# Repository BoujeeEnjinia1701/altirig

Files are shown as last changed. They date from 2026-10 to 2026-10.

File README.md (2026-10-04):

# AltiRig

     

**Area:** Aerial robotics · **TRL:** 3 of 9 (proof of concept on paper) · **Value-engineering target:** about $1,000 USD (estimated cost of the constructable design about $3,865 USD, using surplus steel and a host lab's DC supply and pump) · **Difficulty:** 3 of 5

A test chamber that simulates thin air at 5,000 m so propellers and motors can be proven before going up the mountain.

> CONCEPT, NOT FOR FABRICATION. AltiRig is a TRL 3 design on paper: it has not been built or tested.

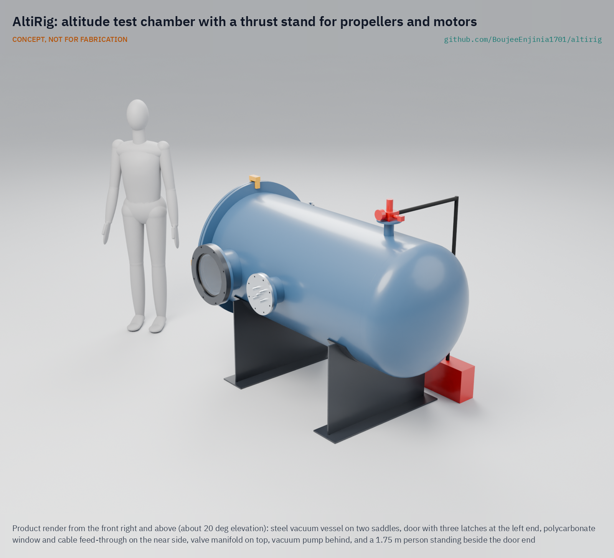
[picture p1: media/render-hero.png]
AltiRig: altitude test chamber with a thrust stand for propellers and motors, product render


[Exploded render](media/render-exploded.png) · [Detail render](media/render-detail.png) · [Interactive 3D model](media/viewer.html) · [Concept blueprint (PDF)](media/concept-blueprint.pdf) · [General arrangement (PDF)](cad/drawings/ALR-DWG-001.pdf) · [Calculations](docs/04-calcs/01-sizing.md) · [Prototype build plan](docs/05-build-plan.md) · [Design decisions](docs/06-design-decisions.md) · [Review note](docs/REVIEW.md)

> **Not certified pressure or test equipment.** AltiRig is a TRL 3 concept, not released for fabrication. It is a vacuum vessel with a spinning propeller inside; see [Safety](#safety).

## Concept rationale

AltiRig is the test chamber of the Kitewright civilian drone family. It is a sealed vessel with a thrust stand inside. A vacuum pump lowers the air pressure until the air density matches 5,000 m, and the stand then measures a propeller and motor's thrust, torque, speed and electrical power as they would be in the Himalaya. The same run can be repeated at any density between sea level and the target altitude.

Proving propellers and motors on the bench before carrying them up a mountain saves expeditions and aircraft. An open, documented chamber that a university lab or a welding shop and maker space can build (value-engineering target USD 1,000; the constructable design is estimated at USD 3,865 with surplus steel and a host lab's DC supply and pump) lets anyone planning high-altitude flights check their numbers first, and lets the Kitewright Lift and Range frames publish thrust data measured, not guessed. ColdCell packs are not tested inside the chamber in this version.

## Burning platform

Propeller thrust depends on air density as well as on the propeller's shape and speed ([Tyto Robotics](https://www.tytorobotics.com/blogs/articles/how-to-measure-propeller-performance-coefficients)). At 5,000 m in the standard atmosphere the density is 0.736 kg/m3, about 60% of the sea-level value of 1.225 kg/m3, and the pressure is 54 kPa ([Engineering ToolBox](https://www.engineeringtoolbox.com/standard-atmosphere-d_604.html)). A drone that hovers comfortably at the workshop can be close to its limit at a Himalayan lake. Our earlier estimate is that at 5,000 m and -20 C a multirotor hovers for only about 47% of its sea-level time (estimate).

Demand to fly this high is real. DJI ran delivery tests between 5,300 m and 6,000 m on Everest in 2024 ([DJI, 2024](https://www.dji.com/media-center/announcements/dji-completes-world-first-drone-delivery-tests-on-mount-everest-en)), and India's glacial lake work takes place above 4,500 m ([ThePrint, 2024](https://theprint.in/india/govt-approves-rs-150-crore-for-glacial-lake-outburst-flood-risk-mitigation-programme-for-4-states/2232525/)). Yet common thrust stands, such as Tyto Robotics' Flight Stand 50, measure thrust, torque and power at the conditions of the room they sit in ([Tyto Robotics](https://www.tytorobotics.com/pages/flight-stand-50)). Commercial altitude chambers exist for testing equipment at low pressure ([Sanatron](https://www.sanatron.com/articles/altitude-test-chamber-how-vacuum-chambers-simulate-high-altitudes.php)), but they are built for industry, not for a small team choosing propellers.

## Where it could be used

### By industry

| Industry | Use |
| --- | --- |
| Drone design and research | Propeller and motor selection for high-altitude multirotors and quadplanes |
| Mountain rescue and disaster agencies | Checking that a drone will hover with margin at the altitude of a call-out before deployment |
| Universities and technical colleges | Teaching lab for propeller aerodynamics and the effect of air density |
| Glaciology and survey | Verifying survey drones before summer campaigns above 4,500 m |
| Battery and electronics testing | Low-pressure checks of battery packs, connectors and electronics for arcing or seal problems |

### By country or region

| Country or region | Why it matters there |
| --- | --- |
| Nepal | Drone delivery tests on Everest ran between 5,300 m and 6,000 m in 2024 ([DJI, 2024](https://www.dji.com/media-center/announcements/dji-completes-world-first-drone-delivery-tests-on-mount-everest-en)). |
| India (Himalaya) | Survey and mitigation work on 189 high-risk glacial lakes takes place above 4,500 m ([ThePrint, 2024](https://theprint.in/india/govt-approves-rs-150-crore-for-glacial-lake-outburst-flood-risk-mitigation-programme-for-4-states/2232525/)). |
| India (Ladakh) | The Gya glacier snout that fed the 2014 outburst flood lies at about 5,450 m ([Science of the Total Environment](https://www.sciencedirect.com/science/article/abs/pii/S0048969720375392)). |
| Pakistan (Karakoram) | The 2018 Broad Peak search found Rick Allen by drone at about 7,500 m ([Explorersweb, 2018](https://explorersweb.com/rick-allen-found-alive-on-broad-peak/)). |

## What sparked the idea

In July 2018 a small consumer drone found the climber Rick Allen alive at about 7,500 m on Broad Peak, 36 hours after he fell from an ice cliff ([Explorersweb, 2018](https://explorersweb.com/rick-allen-found-alive-on-broad-peak/)). That the drone flew at all in air that thin was notable. For the Kitewright family to fly reliably at 5,000 m and above, its propellers and motors need to be tested in that air before they go up, and AltiRig is the bench that makes that possible at sea level.

## Problem

Propellers and motors make much less thrust in the thin air of the high Himalaya, but most makers can only test them at the altitude of their workshop. They find out what works at 5,000 m by flying there, which is slow, costly and risky.

Full problem statement: [docs/01-problem.md](docs/01-problem.md)

## Concept

A sealed test chamber with a thrust stand that pulls the air down to the density of 5,000 m altitude, so makers measure propeller and motor thrust and power as they will be in the Himalaya.

The constructable design is a horizontal steel vessel made from a surplus 813 mm (32 in) pipe offcut and two surplus tank heads, one of them the door, on two saddles. Inside, a flexure thrust stand measures thrust from 0 to 50 N and torque to 2 N m on propellers up to 380 mm. The density of 5,000 m (0.736 kg/m3) is reached at about 61.9 kPa at room temperature in about 3 minutes. The vessel is designed for full vacuum with a collapse factor of 6.7. On paper all twelve requirements are met: an 80 % open baffle keeps the chamber effect (R6) to an estimated 1.8 % to 3.3 %, and the cost (R10), restated by Amish to USD 4,000, is estimated at USD 3,865 (see the [review note](docs/REVIEW.md)).

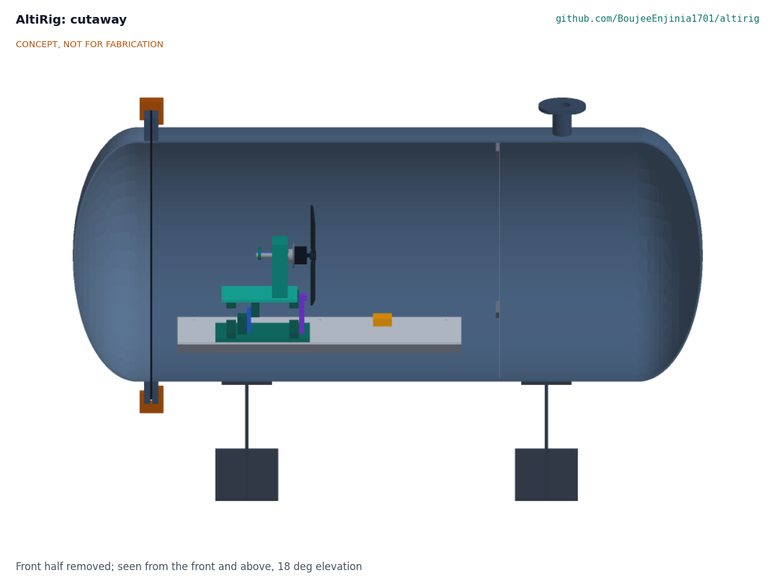
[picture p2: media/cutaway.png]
AltiRig cutaway: stand, propeller, baffle


Full design precis: [docs/02-concept.md](docs/02-concept.md) · Requirements: [docs/03-requirements.md](docs/03-requirements.md)

## Key components

- Pressure vessel: 813 x 6.35 mm steel pipe shell, 2:1 ellipsoidal tank heads, flange rings and a sponge-gasket door held shut by air
- Viewing port: 20 mm polycarbonate window, outside the propeller's fragment zone
- Vacuum pump (the host lab's, 170 L/min), relief valve, normally-open bleed valve and gauge on one manifold
- Thrust and torque stand: spring-steel flexures, 10 kg thrust cell, torque head on bearings with a 5 kg cell
- Speed sensor: optical, one pulse a turn
- Pressure, temperature and humidity sensors on the deck
- Sealed feed-through plate with potted IP68 cable glands
- Removable 80 % open perforated baffle
- Control cabinet: logger, contactor for the host lab's 1,500 W motor supply, emergency stop, door interlock and arming key

## Building the prototype

The [prototype build plan](docs/05-build-plan.md) shows how to make each of the twenty-two made parts, with a making sketch for each, ten joint close-ups and twenty assembly steps. The vessel is cut and welded by a welding shop from surplus pipe, plate and two surplus tank heads; the stand is cut, drilled and bored from aluminium and spring-steel shim. Before any pump-down a qualified engineer reviews the vessel calculation, and the first pump-down is a proof test behind a guard. The plan is a plan, not yet built.

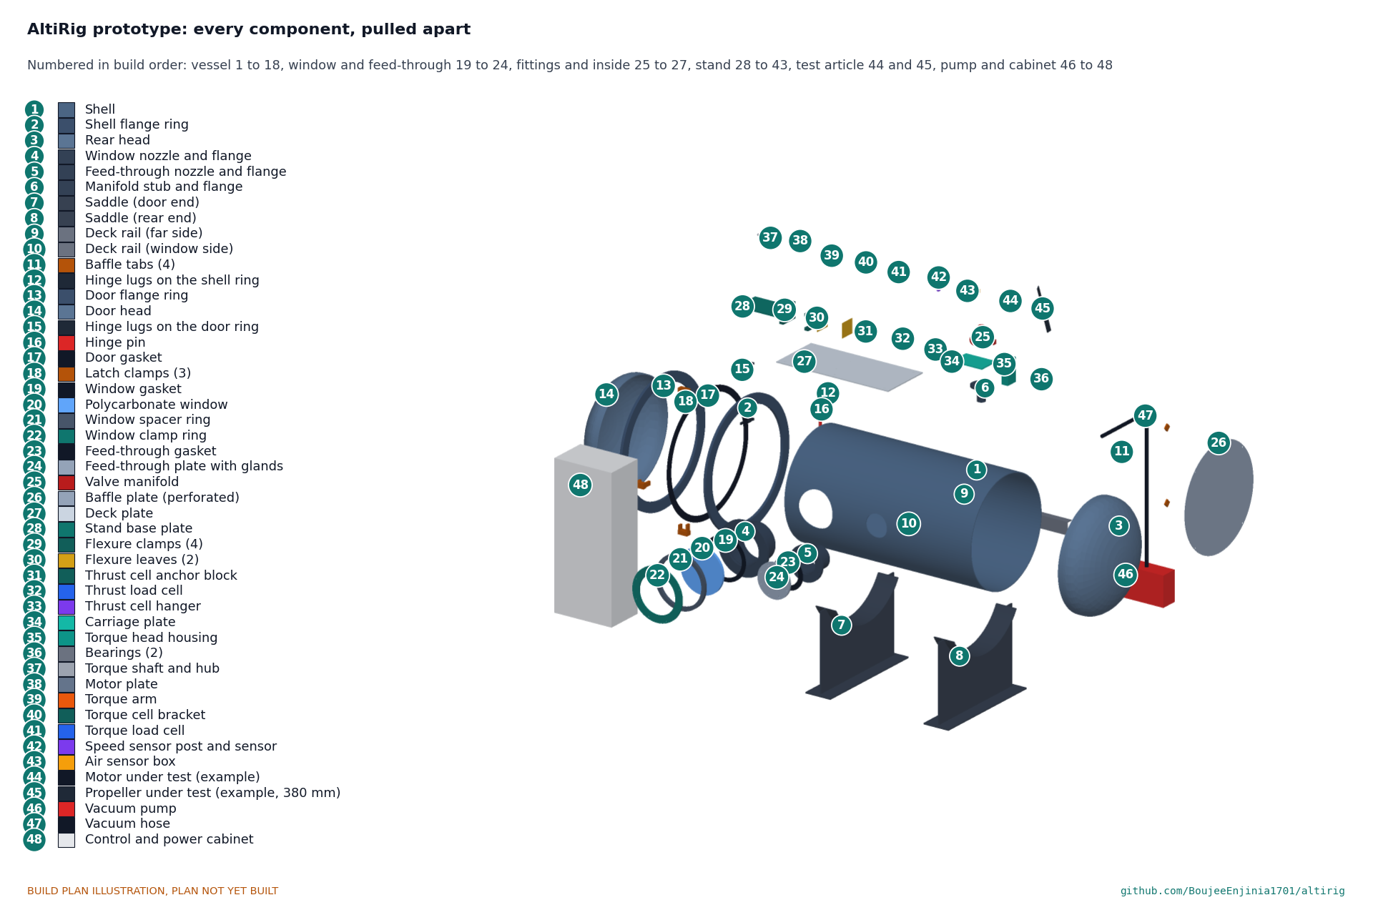
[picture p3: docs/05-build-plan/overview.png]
Every component of AltiRig, pulled apart and numbered in build order


## Safety

> Published as an open engineering reference, not certified pressure or test equipment.
>
> The chamber is a vacuum vessel: at the 5,000 m density point the outside air pushes on it with about 39 kPa, and with up to 55 kPa at the relief setting, roughly 4 to 5.6 tonnes-force per square metre of wall. Collapse or window failure can throw fragments. The vessel is designed for full vacuum with a collapse factor of 6.7, a relief valve stops the chamber at 46.3 kPa absolute, the window is polycarbonate (never acrylic or glass), and the first pump-down is a proof test behind a guard after a qualified engineer has reviewed the calculation.
>
> The door is held shut by up to 24 kN under vacuum. Vent the chamber before unlatching it; never force it.
>
> Spinning propellers can shatter. The window and feed-through sit outside the propeller's fragment zone, the steel shell contains a broken blade, and the motor can only be armed with the door latched and the key turned.
>
> No lithium or sodium-ion pack goes inside the chamber in this version: a fire in a closed vessel is a pressure and fume hazard.
>
> The pump and motor supply run from mains through a 30 mA residual current device with the vessel earthed; the emergency stop removes motor and pump power and the bleed valve opens on loss of power.
>
> This design is published as an open engineering reference. It is not certified equipment.

## Repository layout

| Folder | Contents |
| --- | --- |
| `docs/` | Problem, concept, requirements, calculations and design decisions |
| `cad/src/` | build123d Python source, the source of truth for all geometry |
| `cad/step/`, `cad/stl/` | Exported models for FreeCAD, other CAD tools and printing |
| `cad/drawings/` | 2D sketches and dimensioned drawings |
| `bom/` | Bill of materials |
| `electronics/` | KiCad schematics and PCB layouts |
| `firmware/` | Microcontroller code |
| `media/` | Renders, perspectives and photos |
| `build-log/` | Dated prototyping notes |

## Documentation

Controlled documents follow the portfolio [documentation standard](.kit/STANDARDS.md). Each carries a document ID (ALR-PRC-001 for the precis), a version and a revision history. Branded PDFs are built with `python .kit/render.py` and attached to GitHub Releases when a document is tagged, for example `ALR-PRC-001/v1.0`.

## Credits

Designed by Amish Chadha at Design Molecule Labs. See [CONTRIBUTORS.md](CONTRIBUTORS.md) for roles. To cite this design, use [CITATION.cff](CITATION.cff) (GitHub shows it as "Cite this repository").

AI assistance (Claude) was used to accelerate prototype documentation and first-pass research. Design direction and all decisions are Amish Chadha's, recorded in this repository's decision records (`docs/decisions/`).

## Licenses

- **Hardware** (CAD, drawings, BOM, electronics): [CERN-OHL-S v2](LICENSE)
- **Software** (firmware, scripts, notebooks): [MIT](LICENSE-SOFTWARE)

A project of the [Design Molecule](https://designmolecule.com) lab.

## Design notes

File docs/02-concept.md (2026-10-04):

---
doc_id: ALR-PRC-001
title: AltiRig design precis
project: AltiRig
doc_type: Precis
version: "0.4"
status: Draft
date: '2026-10-03'
author: Amish Chadha
license: CERN-OHL-S-2.0
revisions:
- version: "0.1"
  date: '2026-09-30'
  author: Amish Chadha
  change: Initial scaffold
- version: "0.2"
  date: '2026-10-03'
  author: Amish Chadha
  change: TRL 2 concept; vessel type, stand, density matching, safety design and media decided under Amish's 2026-10-03 pre-approval (ALR-DDR-001)
- version: "0.3"
  date: '2026-10-03'
  author: Amish Chadha
  change: TRL 3; numbers from ALR-CAL-001 and the constructable design (ALR-DDR-002)
- version: "0.4"
  date: '2026-10-03'
  author: Amish Chadha
  change: "Amish's decisions 41B (80 % open baffle) and 42B (surplus pipe and heads, host lab's DC supply and pump), ALR-DDR-003"
---

# AltiRig design precis

A test chamber that simulates thin air at 5,000 m so propellers and motors can be proven before going up the mountain.

AltiRig is a horizontal steel vacuum vessel, 813 mm in diameter and about 2 m long, with a flexure thrust stand inside. A vacuum pump lowers the pressure until the air inside has the density of 5,000 m (0.736 kg/m3, about 61.9 kPa at 20 °C), and the stand measures a propeller's thrust, torque and speed with the motor's voltage and current. The vessel is built from a surplus steel pipe offcut and two surplus tank heads, one of which is the door; air pressure holds the door shut while the chamber is under vacuum.

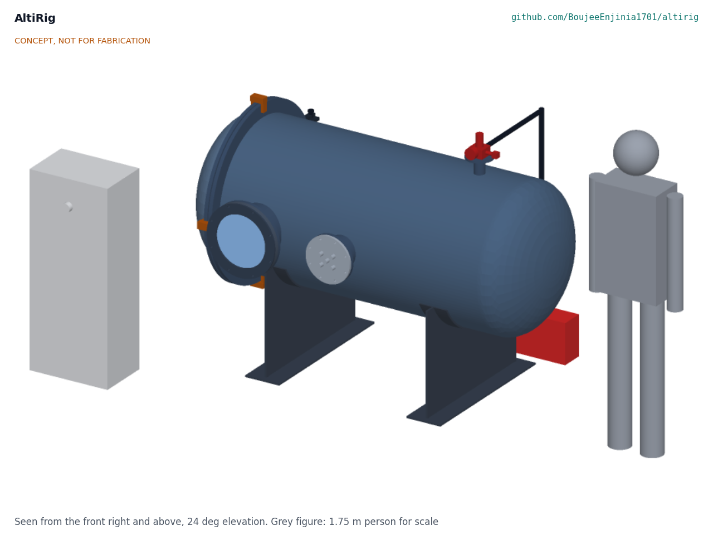
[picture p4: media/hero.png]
AltiRig concept with a 1.75 m person for scale


*Figure 1. AltiRig, seen from the front right and above: vessel on two saddles, door and latches at the left end, window and feed-through on the near side, valve manifold on top, pump behind, control cabinet in front.*

## How it works

The motor and propeller under test sit on the axis of the vessel, 510 mm in from the door, blowing toward the rear head. The operator closes the door, latches it and starts the pump. The controller reads two pressure sensors and two temperature probes inside, works out the air density, and holds it at the chosen value by switching the pump and opening a bleed valve that lets room air back in. As the motor runs, its heat warms the air; the controller raises the pressure a little to keep the density steady.

The propeller's thrust moves the carriage of the stand by about a tenth of a millimetre on two spring-steel leaves, and a load cell between the carriage and the base measures it. The motor is mounted on a shaft that turns freely in two bearings; its reaction torque presses an arm onto a second load cell. An optical sensor counts the blades. Motor power comes from the host lab's 1,500 W DC supply, switched by the interlocked contactor in the control cabinet, through a speed controller and a sealed feed-through plate. Everything is logged to CSV at 20 Hz.

Inside a closed vessel the propeller drives a loop of air: down the middle, through an 80 % open perforated baffle, round the rear head and back along the wall. To find what the loop does to the readings, each propeller is also run at ambient pressure and compared with an open-air stand; that comparison is published with the data.

AltiRig cutaway

*Figure 2. Cutaway with the window side removed: stand and motor on the deck at the door end, the propeller plane, the baffle and the rear head.*

## Components

*Table 1. Main components (numbers match `bom/bom.csv`).*

| # | Component | Role |
| --- | --- | --- |
| 1 | Shell | 813 x 6.35 mm steel pipe offcut, 1,500 mm long; the body of the vessel |
| 2 | Flange rings | 20 mm steel rings on the shell end and on the door; the door seals on a sponge gasket between them |
| 3 | Dished heads | Two bought 2:1 ellipsoidal heads: one welded to the rear, one is the door |
| 4 | Window nozzle and flange | 10 in heavy-wall stub with a flange for the window |
| 5 | Feed-through nozzle and flange | 6 in heavy-wall stub with a flange for the cable plate |
| 6 | Manifold stub | 2 in stub on top for the valve manifold |
| 7 | Saddles | Two welded steel saddles carrying the vessel at axis height 800 mm |
| 8, 9 | Deck rails and baffle tabs | Welded inside to carry the deck and the baffle |
| 10 | Hinge | Lugs and a 20 mm pin; the door swings to the far side |
| 11, 12 | Gaskets and latch clamps | EPDM gaskets; three latches pull the door on for the first seal |
| 13, 14 | Window, spacer and clamp rings | 20 mm polycarbonate window, 340 mm, clamped on its flange |
| 15 | Feed-through plate | Aluminium plate with five potted IP68 cable glands |
| 16, 17 | Deck plate and baffle plate | Aluminium deck for the stand; 80 % open perforated baffle (22 mm square holes), removable |
| 18 to 25 | Thrust stand | Base, two flexure leaves and clamps, carriage, thrust cell, torque head on bearings, torque arm and cell, speed sensor |
| 26, 27 | Motor and propeller under test | Example 6S motor and 15 x 5 in propeller; users bring their own |
| 28 | Valve manifold | Relief valve (opens 55 kPa below atmosphere), gauge, normally-open bleed valve, vent and isolation valves |
| 29 | Vacuum pump and hose | The host lab's 170 L/min single-stage rotary vane pump (no less than 140 L/min); bought hose |
| 30 to 35 | Cabinet, sensors, supply, speed controller, controller, safety controls | Mains protection, the host lab's 1,500 W motor supply (switched by the cabinet's contactor), logger, emergency stop, door interlock and arming key |

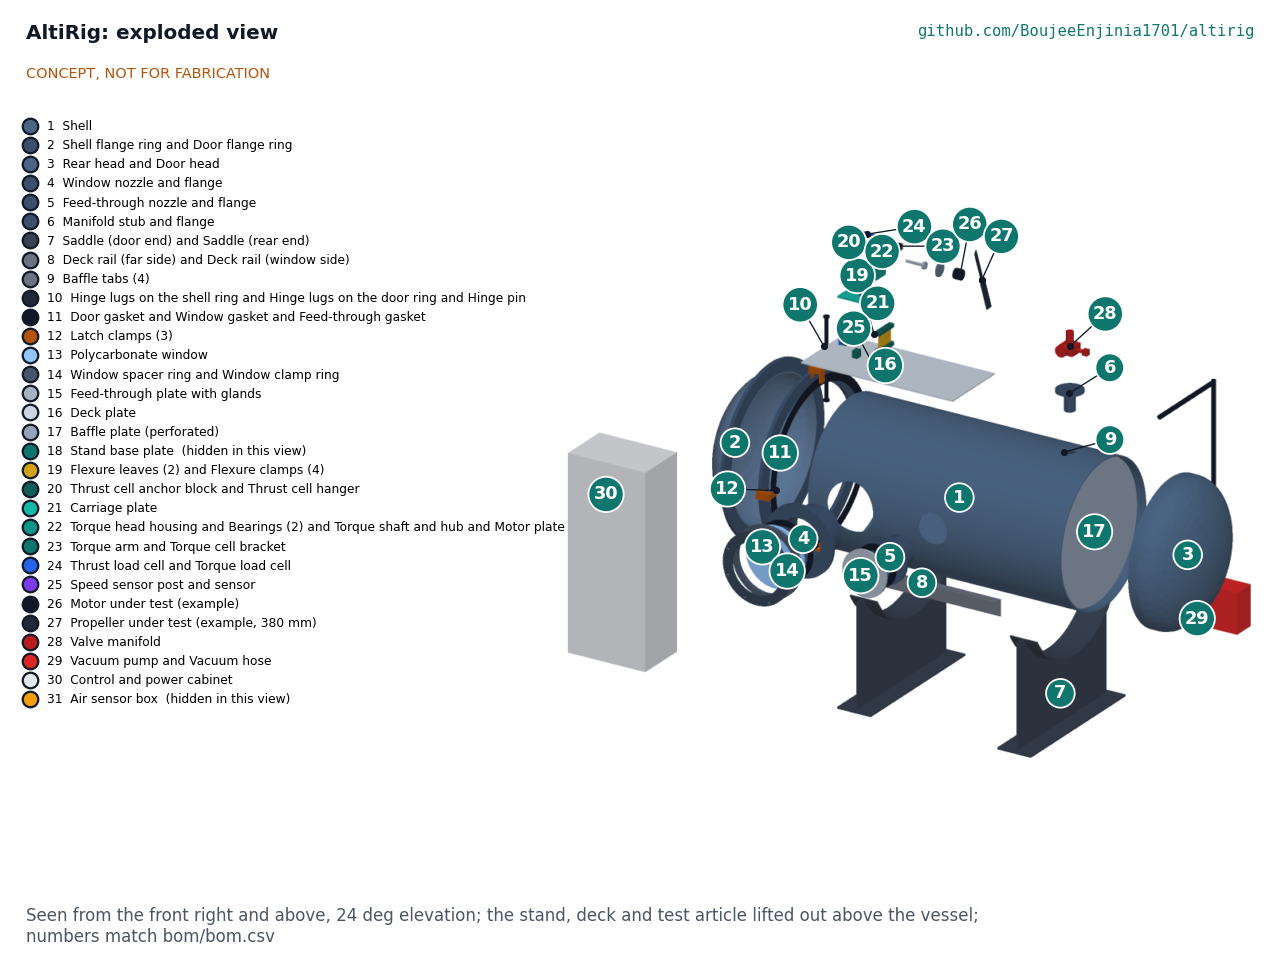
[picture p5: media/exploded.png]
AltiRig exploded view


*Figure 3. Exploded view; numbers match the bill of materials.*

## Key design choices

All were decided on 2026-10-03 under Amish's pre-approval and are argued in ALR-DDR-001 (TRL 2 review) and ALR-DDR-002 (design for construction).

- **Match density, not pressure.** Thrust and power depend on density. At room temperature the density of 5,000 m is reached at 61.9 kPa, not at the 54.0 kPa of the real atmosphere there. Pressure and temperature are logged so either can be reported.
- **A pipe vessel with tank heads, designed for full vacuum.** Thin drums collapse and flat panels need heavy ribs. A 6.35 mm pipe with dished heads has a collapse factor of 6.7 even at full vacuum, so a stuck relief valve cannot collapse it.
- **The door is a tank head held shut by the air.** At the 5,000 m point the air presses the door shut with 24 kN, so it cannot be opened until the chamber is vented.
- **A flexure stand, not rails.** Two spring-steel leaves carry the carriage with no sliding friction; the small share of thrust they carry is calibrated out.
- **Window and feed-through outside the propeller's fragment zone.** Both sit more than 18° from the propeller plane; the steel shell contains a broken blade.
- **No batteries inside the chamber in the first version.** The motor is powered from outside through the feed-through, so a battery fire cannot happen inside a closed vessel.

## First-order numbers

From ALR-CAL-001; assumptions are stated there.

*Table 2. First-order numbers.*

| Quantity | Value |
| --- | --- |
| Density range | Ambient down to 0.660 kg/m3 (6,000 m) at up to 30 °C; relief at 46.3 kPa |
| Free volume | 0.93 m3 |
| Pump-down to 54 kPa | 4.0 min |
| Shell collapse factor at full vacuum | 6.7 (heads 40, window 7.1 on yield) |
| Door force at the 5,000 m point | 24 kN |
| Thrust range and error | 0 to 50 N, 0.13 N (0.27 % of full scale) |
| Torque and speed error | 0.28 % of 2 N m; 0.02 % |
| Density error | 0.6 % |
| Chamber effect (estimate) | 1.8 % to 3.3 % more thrust than open air with the 80 % open baffle (R6 target 5 %) |
| Mass | About 470 kg vessel, about 585 kg with pump and cabinet |
| Cost | Value-engineering target: USD 1,000. Estimated cost of the constructable design: USD 3,865 (USD 2,865 over the target), with a surplus pipe and heads and the host lab's DC supply and pump; R10 restated to USD 4,000 (decision 42B) |

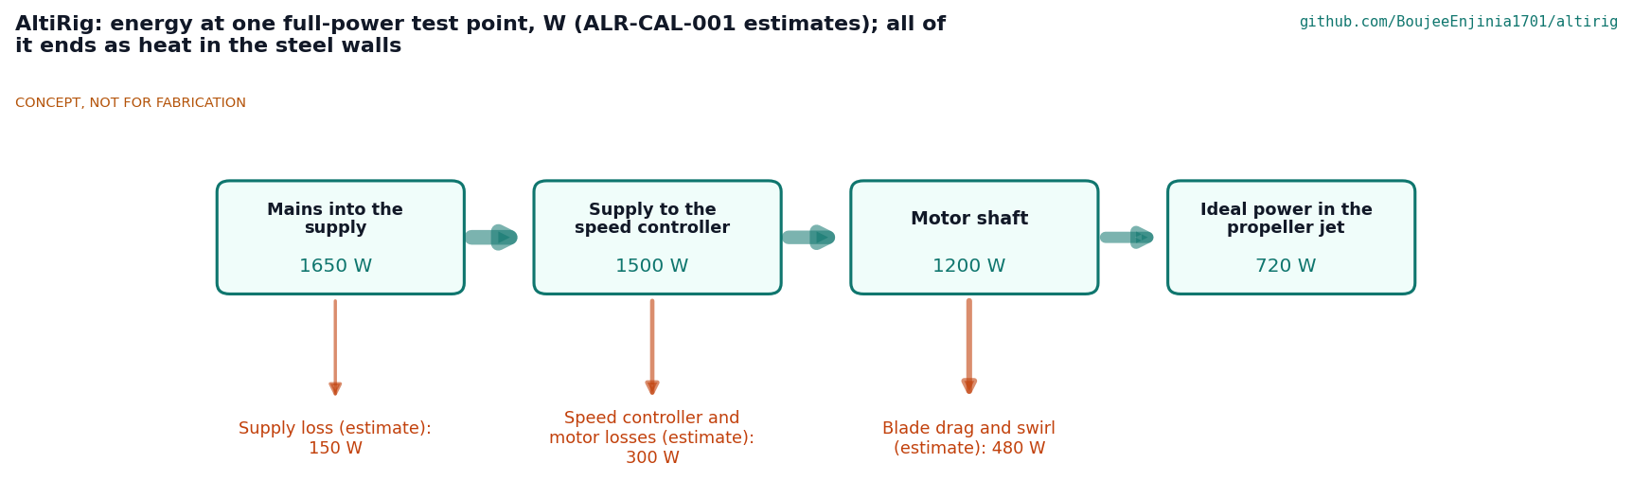
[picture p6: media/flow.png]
Energy flow at one full-power test point


*Figure 4. Energy at one full-power test point; every watt ends as heat in the steel walls.*

## Patent design-arounds

From the preliminary patent, trademark and prior-art screen (not legal advice):

- None identified in the preliminary screen.

## Shared blocks

- Kitewright Lift and Kitewright Range (propulsion under test; they publish their propulsion kits using AltiRig data)
- ColdCell (packs are not tested inside the chamber in the first version; see Safety)
- CalRig proof-load method for calibrating the load cells, if adopted

## Safety

> **Safety:** AltiRig is a vacuum vessel with a spinning propeller inside, run from mains power.
>
> - **Vacuum (pressure) hazard.** At the 5,000 m point the air outside pushes on the vessel with 39 kPa, about 4 tonnes-force on each square metre. Collapse or a failed window can throw fragments. The vessel is designed for full vacuum with a collapse factor of 6.7, the relief valve stops the chamber below 46.3 kPa, and the first pump-down is a proof test behind a guard with nobody in line with the window. Only polycarbonate is used for the window; acrylic and glass shatter.
> - **Door.** The door weighs about 72 kg and is held shut by up to 24 kN. Never force it: vent first through the bleed or vent valve, then unlatch.
> - **Spinning propeller.** A propeller can break at speed; fragments fly in its own plane. The window and feed-through are outside that zone, the steel shell contains it, and the motor can only be armed with the door latched and the key turned.
> - **Batteries.** No lithium or sodium-ion pack goes inside the chamber in this version. A battery fire in a closed vessel raises the pressure and the fumes are toxic; battery tests need a vent and fire plan that is not part of this design.
> - **Mains.** The pump and the motor supply run from mains through a 30 mA residual current device with the vessel earthed. The emergency stop removes motor and pump power, and the bleed valve opens when power is lost.
> - **Noise and oil mist.** The pump exhausts oil mist; lead the exhaust outdoors. Wear hearing protection near the running propeller.
>
> AltiRig is published as an open engineering reference. It is not certified pressure equipment or test equipment.

## Open questions

None are open in the design. Decisions still to be made are kept in the design decisions register (`docs/06-design-decisions.md`), and items to confirm when parts are bought are listed there.

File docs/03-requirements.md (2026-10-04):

---
doc_id: ALR-REQ-001
title: AltiRig requirements
project: AltiRig
doc_type: Requirements
version: "0.4"
status: Draft
date: '2026-10-03'
author: Amish Chadha
license: CERN-OHL-S-2.0
revisions:
- version: "0.1"
  date: '2026-09-30'
  author: Amish Chadha
  change: Initial scaffold
- version: "0.2"
  date: '2026-10-03'
  author: Amish Chadha
  change: TRL 2 review; concept status for every requirement; R11 interlocks and R12 over-vacuum protection added (ALR-DDR-001)
- version: "0.3"
  date: '2026-10-03'
  author: Amish Chadha
  change: TRL 3 status from the calculations (ALR-CAL-001) and the constructable design (ALR-DDR-002)
- version: "0.4"
  date: '2026-10-03'
  author: Amish Chadha
  change: "Amish's decisions 41B (80 % open baffle; R6 met on paper at 1.8 % to 3.3 %) and 42B (surplus pipe and heads, host lab's DC supply and pump; R10 restated to USD 4,000 and met at USD 3,865), ALR-DDR-003"
---

# AltiRig requirements

All twelve requirements are met on paper by the constructable design, R10 as restated on 2026-10-03. Targets are unchanged from the scaffold except for the two safety requirements added at the TRL 2 review (R11 and R12) and R10, restated by Amish's decision 42B. Status is on paper only: every requirement is verified by test at TRL 4.

On 2026-10-03 Amish decided the two requirement decisions put to him at TRL 3 as recommended. Amish, 2026-10-03: "i agree with all the 46 recommendations you provided. please proceed." For AltiRig these are 41B (R6: an 80 % open baffle) and 42B (R10: a surplus pipe and heads and the host lab's DC supply and pump, with the cost target restated), recorded in ALR-DDR-003.

*Table 1. Requirements and their status at TRL 3.*

| ID | Requirement | Target | Verification (TRL 4 or later) | Status at TRL 3 |
| --- | --- | --- | --- | --- |
| R1 | Density range | Hold any air density from ambient down to 0.74 kg/m3 (5,000 m equivalent) at room temperature | Pressure and temperature log over a 10 min hold at several set points | Met on paper: 0.736 kg/m3 needs 61.9 kPa at 20 °C; the pump reaches far lower and the relief valve stops at 46.3 kPa (ALR-CAL-001, A) |
| R2 | Density control | Density held within plus or minus 1% of set point during a run | Logged density during motor runs | Met on paper: error budget 0.6 % (ALR-CAL-001, D) |
| R3 | Thrust range and accuracy | 0 to 50 N thrust with error no more than 1% of full scale | Calibration with certified masses before and after a test series | Met on paper: flexure stand with a 10 kg cell, error budget 0.13 N, 0.27 % (ALR-CAL-001, E) |
| R4 | Torque and speed | Torque 0 to 2 N m within 2%; speed within 0.5% | Calibration arm with masses; optical tachometer cross-check | Met on paper: torque error 0.3 %, speed 0.02 % (ALR-CAL-001, E) |
| R5 | Propeller size | Propellers up to 380 mm (15 in) diameter | Fit check and clearance measurement | Met on paper: 210 mm from tip to wall, 80 mm to the deck (ALR-CAL-001, E) |
| R6 | Chamber effect | At ambient pressure, chamber thrust within 5% of an open-air stand for the same propeller and speed | Side-by-side comparison tests | Met on paper (decision 41B): estimated 1.8 % to 3.3 % high with the 80 % open baffle, was 2.9 % to 5.3 % with the 63 % baffle (ALR-CAL-001, F); confirmed by the TRL 4 comparison runs with and without the baffle |
| R7 | Vessel safety factor | Collapse pressure at least 4 times the maximum working pressure difference (target) | Calculation reviewed by a qualified engineer, then proof test behind a guard | Met on paper, at full vacuum: shell 6.7, heads 40, window 7.1 on yield (ALR-CAL-001, B) |
| R8 | Pump-down time | Ambient to 54 kPa in no more than 5 min | Timed pump-down with pressure log | Met on paper: 4.0 min with a 170 L/min pump (ALR-CAL-001, C) |
| R9 | Data output | Results saved as CSV with density, thrust, torque, speed, voltage and current at 10 Hz or more | Inspection of logged files | Met on paper: 20 Hz logging, amplifiers at 80 Hz (ALR-CAL-001, G) |
| R10 | Cost | Restated 2026-10-03 (decision 42B): complete rig at or below USD 4,000, built with a surplus pipe offcut and tank heads that pass the roundness and thickness checks, and the host lab's existing DC supply and vacuum pump; the USD 1,000 value-engineering target is kept as a control figure. Was: complete rig at or below USD 1,000 | Costed bill of materials | Met as restated: USD 3,865, USD 135 under USD 4,000 and USD 2,865 over the value-engineering target (ALR-CAL-001, H) |
| R11 | Interlocks | The motor can be powered only with the door latched and the arming key turned; the emergency stop removes motor and pump power; the bleed valve opens and vents the chamber on loss of power | Function check of each interlock before first power | Met on paper by design (ALR-BLD-001, sections 4 and 6); the door is also held shut by 24 kN of air load at the 5,000 m point |
| R12 | Over-vacuum protection | A relief valve stops the chamber going below 46.3 kPa absolute (55 kPa below atmosphere); the vessel is still designed for full vacuum | Relief valve set and checked against the gauge before first pump-down | Met on paper (ALR-CAL-001, A and B) |

## Requirements not met or at risk

None on paper. The two that were (R6 at risk, R10 not met) were decided by Amish on 2026-10-03: Amish, 2026-10-03: "i agree with all the 46 recommendations you provided. please proceed."

- **R6, decision 41B.** The closed loop of air inside the vessel adds a little resistance to the propeller's own flow, so the propeller is expected to give slightly more thrust in the chamber than in open air. With the 80 % open baffle two simple models give 1.8 % and 3.3 %, inside the 5 % target. The TRL 4 comparison runs decide it; the 1,016 mm vessel is held in reserve if they show more than 5 %.
- **R10, decision 42B.** Restated to USD 4,000 with surplus vessel steel and the host lab's DC supply and pump; estimated USD 3,865. It depends on the surplus pipe and heads passing the roundness and thickness checks, and on the host lab having a DC supply of at least 1,500 W and a pump of at least about 140 L/min. Buying a new pipe, heads, pump and supply instead would cost about USD 4,930; buying only a new pump and supply, about USD 4,400.

## Assumptions

- Matching air density is the main effect; the small differences in viscosity and speed of sound between a room-temperature chamber and real air at 5,000 m and -17.5 °C are second order for small propellers (to be checked). Blade Reynolds number falls by about 39 % at 5,000 m density (ALR-CAL-001, E), which the chamber reproduces because density, not pressure, is matched.
- A surplus or new-cut 813 mm steel pipe offcut and two tank heads can be bought; the out-of-roundness of the pipe is no more than 1 % of its diameter (to confirm when bought).
- The chamber effect is measured by side-by-side runs at ambient pressure and recorded with every published data set.
- Earlier physics estimate: hover time at 5,000 m and -20 °C is about 47 % of sea level; AltiRig will test the aerodynamic share of that estimate.

> **Safety:** R7, R11 and R12 are safety requirements. They are met on paper only; no pump-down or motor run is made until the safety stops in the build plan (ALR-BLD-001, section 6) are passed and a qualified engineer has reviewed the vessel calculation.

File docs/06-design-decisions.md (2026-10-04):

---
doc_id: ALR-DEC-001
title: AltiRig design decisions register
project: AltiRig
doc_type: Design decisions register
version: "0.2"
status: Draft
date: '2026-10-03'
author: Amish Chadha
license: CERN-OHL-S-2.0
revisions:
- version: "0.1"
  date: '2026-10-03'
  author: Amish Chadha
  change: Register opened at TRL 3; design decisions made under Amish's 2026-10-03 pre-approvals; R6 and R10 posed to Amish
- version: "0.2"
  date: '2026-10-03'
  author: Amish Chadha
  change: "Amish's decisions 41B (80 % open baffle) and 42B (surplus pipe and heads, host lab's DC supply and pump; R10 restated) moved to Decisions made (ALR-DDR-003)"
---

# AltiRig design decisions register

Every design decision still to be made, and every decision made, in one place. Each decision is argued in full in its decision record under `docs/decisions/`; this register is the index Amish works from. The build plan (`docs/05-build-plan.md`) describes the design as it stands.

> **Safety:** AltiRig is a vacuum vessel with a spinning propeller inside, run from mains power. Every decision that touches safety took the conservative option, and the evidence that would relax it is named in its record. Nothing here makes the chamber certified pressure or test equipment.

## Open decisions

None. The two requirement decisions put to Amish at TRL 3 (R6 and R10) were decided on 2026-10-03 as recommended (41B and 42B, below and in [ALR-DDR-003](decisions/0003-requirement-decisions.md)); carrying them out raised no new question for Amish. What the host lab's pump and supply must meet is listed under To confirm.

## To confirm when parts are bought

| # | What to confirm | Why it matters | Source |
| --- | --- | --- | --- |
| 1 | The surplus pipe offcut's out-of-roundness (no more than 8 mm between largest and smallest diameter) and wall thickness (6.35 mm, no less than 5.9 mm at any point), checked before buying | The shell's collapse factor of 6.7 assumes both; decision 42B makes the pipe surplus | ALR-CAL-001 B; ALR-DDR-003 |
| 2 | The surplus or overstock tank heads' skirt length (40 mm), thickness (no less than 5.9 mm) and outside diameter match the pipe, checked before buying | The door ring fits over the skirt; the rear head butts to the pipe | ALR-DDR-002, C2; ALR-DDR-003 |
| 3 | Flatness of both flange ring faces after welding (within 1 mm) | The 6 mm sponge must seal the door at the first pump-down | ALR-BLD-001, 3.2 |
| 4 | The relief valve's adjustable range covers 55 kPa below atmosphere and it is rated for vacuum service | R12 | ALR-DDR-001, D4 |
| 5 | The load cells' stiffness (deflection at full scale) and combined error class | Sets the share of thrust carried by the leaves (2.9 % assumed) and the error budgets | ALR-CAL-001 E |
| 6 | The host lab's pump: rated at least 140 L/min (170 L/min as calculated), with a thermal overload and an oil-mist exhaust filter; its speed curve between 50 and 100 kPa inlet | Pump-down time (R8) assumes 85 % of the rating; 140 L/min gives about 4.9 min against 5 min | ALR-CAL-001 C and H; ALR-DDR-003 |
| 7 | The example propeller's static coefficients (0.10 and 0.042 assumed) | Speeds, power and torque at 50 N; the supply limit of about 44 N at 5,000 m density | ALR-CAL-001 E |
| 8 | Latch clamps hold at least 3 kN | The first seal needs about 2.1 kN each | ALR-CAL-001 B |
| 9 | The host lab's DC supply gives at least 1,500 W at 24 V (adjustable 20 to 28 V), has overcurrent protection, and can be switched by the cabinet's motor contactor | A smaller supply lowers the thrust reached at 5,000 m density below about 44 N; R11 needs the contactor to cut it | ALR-CAL-001 E and H; ALR-DDR-003 |

## Value engineering

Value-engineering target: USD 1,000 (a hypothetical control target, not a limit). Estimated cost of the constructable design: USD 3,865 (USD 2,865 over the target). R10 is restated to USD 4,000 by Amish's decision 42B, and USD 3,865 is USD 135 under it. Main cost drivers and savings still worth trying:

- The vessel steel, heads and nozzles (about USD 1,270 with the surplus pipe and heads, saddles, rings, rails, tabs and window rings) and the welding labour (USD 650). A used air receiver of the same size with its own heads is the next saving worth pricing.
- The speed controller and power sensor (USD 100) and the safety controls and cabinet (USD 360). The host lab's DC supply is used (decision 42B), keeping the interlocked contactor.
- The valve manifold (USD 220) and hose (USD 45). The host lab's pump is used (decision 42B).
- The thrust stand itself is cheap (about USD 300 including the load cells); it is not where the money goes.

## Decisions made

| Date | Decision | Decided by | Record |
| --- | --- | --- | --- |
| 2026-10-03 | TRL 2 review items D1 to D14: match density not pressure, pipe and tank-head vessel, design for full vacuum, R12 relief valve, R11 interlocks, polycarbonate window outside the fragment zone, flexure stand, room temperature only, removable baffle with comparison runs, no batteries inside, external motor supply, propeller kit left to Lift and Range, shared blocks, not-certified notice with engineer review and proof pump-down | Amish: "start with the first 14 repos from the list of 29 projects. I pre-approve the batch runs along with any recommendations you come up with. I also accept any cost overruns or variations from the assumed scope cost." and "Proceed with the remaining 15 scaffolds" | [ALR-DDR-001](decisions/0001-trl2-review-decisions.md) |
| 2026-10-03 | Co-design: the first candidate partner to approach is the Department of Aerospace Engineering, IIT Kanpur, then Kathmandu University; first candidate region the Nepal and Indian Himalaya; candidates, not agreed | Amish, same pre-approvals | [ALR-DDR-001](decisions/0001-trl2-review-decisions.md), D11 |
| 2026-10-03 | Design for construction C1 to C17: pipe shell, flat flange rings with a sponge gasket, set-in heavy-wall nozzles, window stack with a spacer ring, potted feed-through plate, saddles, rails and bolted deck, bolted baffle on tabs, hinge and latches, flexure stand with an upright cell, torque head on bearings, speed post, manifold on a stub flange, normally-open bleed valve, feed-through placement, pump and cabinet placement | Amish, same pre-approvals | [ALR-DDR-002](decisions/0002-design-for-construction.md) |
| 2026-10-03 | Cost overrun against the value-engineering target accepted; `budget_usd` left at USD 1,000 | Amish, same pre-approval ("I also accept any cost overruns") | This register, Value engineering |
| 2026-10-03 | 41B, R6: an 80 % open baffle (2 mm sheet, 22 mm square holes on a 24.5 mm pitch) on the same tabs; chamber effect now 1.8 % to 3.3 % against 5 %; the 1,016 mm vessel held in reserve if the TRL 4 comparison shows more than 5 % | Amish, 2026-10-03: "i agree with all the 46 recommendations you provided. please proceed." | [ALR-DDR-003](decisions/0003-requirement-decisions.md) |
| 2026-10-03 | 42B, R10: surplus pipe offcut and tank heads (after the roundness and thickness checks) and the host lab's DC supply and vacuum pump; cost USD 3,865; R10 restated to "complete rig at or below USD 4,000 with surplus pipe and heads and the host lab's DC supply and pump" | Amish, 2026-10-03: "i agree with all the 46 recommendations you provided. please proceed." | [ALR-DDR-003](decisions/0003-requirement-decisions.md) |

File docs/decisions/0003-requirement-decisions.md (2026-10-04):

---
doc_id: ALR-DDR-003
title: AltiRig requirement decisions (R6, R10)
project: AltiRig
doc_type: Design decision record
version: "0.1"
status: Draft
date: '2026-10-03'
author: Amish Chadha
license: CERN-OHL-S-2.0
revisions:
- version: "0.1"
  date: '2026-10-03'
  author: Amish Chadha
  change: Amish's requirement decisions 41B and 42B carried out
---

# 0003: Requirement decisions on the chamber effect and cost

- **Date:** 2026-10-03
- **Status:** accepted
- **Decided by:** Amish Chadha, 2026-10-03, accepting every recommendation put to him in the second round of requirement decisions: "i agree with all the 46 recommendations you provided. please proceed." For AltiRig: 41B (R6) and 42B (R10).

> **Safety:** Neither decision changes the vessel's design or its safety case. The baffle is inside the vessel and carries no pressure. Surplus pipe and heads are accepted only after the roundness and thickness checks on which the shell's collapse factor of 6.7 depends, and the host lab's DC supply is always switched through the cabinet's interlocked contactor and emergency stop (R11). The host lab's pump must have a thermal overload and an oil-mist exhaust filter led outdoors.

## Context

At TRL 3 (ALR-CAL-001 v0.2) two requirements were at risk or not met on paper. R6 was at risk: with the 63 % open baffle the chamber was estimated to give 2.9 % (same power) to 5.3 % (same speed) more thrust than open air, against a 5 % target. R10 was not met: USD 4,920 against the USD 1,000 value-engineering target. Each was put to Amish as state, options and a recommendation in `docs/REVIEW.md`.

## Options considered

- **R6 (decision 41):** A: keep the 63 % baffle. B (chosen): an 80 % open baffle on the same tabs. C: a 1,016 mm (40 in) vessel with the 63 % baffle.
- **R10 (decision 42):** A: keep the parts as specified (USD 4,920). B (chosen): surplus pipe offcut and tank heads, the host lab's existing DC supply and a workshop vacuum pump with a thermal overload and exhaust filter (about USD 3,700 to 4,000). C: a 610 mm (24 in) vessel for propellers up to about 280 mm (R5 no longer met).

## Decision

1. **41B.** The baffle (BOM line 17) is 2 mm perforated steel with 22 mm square holes on a 24.5 mm square pitch: 80.6 % open, 2.5 mm bars, cut to the same 790 mm disc and bolted to the same four tabs. About 1.5 kg; USD 85 (USD 10 more). The 1,016 mm vessel is held in reserve if the TRL 4 comparison runs still show more than 5 %.
2. **42B.** The shell (line 1) is a surplus pipe offcut (USD 150, was USD 420) and the two heads (line 3) are second-hand or overstock (USD 130 each, was USD 260). The host lab provides its vacuum pump (line 29: only the hose, clamps and adapter are bought, USD 45, was USD 260) and its DC supply (line 32: USD 0, was USD 320). The surplus pipe and heads pass the checks in the register before purchase; the pump is rated no less than 140 L/min; the supply gives at least 1,500 W at 24 V and is switched by the cabinet's contactor.
3. **R10 restated** in `docs/03-requirements.md` v0.4: complete rig at or below USD 4,000, built with a surplus pipe offcut and tank heads that pass the roundness and thickness checks, and the host lab's existing DC supply and vacuum pump; the USD 1,000 value-engineering target is kept as a control figure (`budget_usd` unchanged).

## Results (ALR-CAL-001 v0.3)

| Requirement | Before | After | Status |
| --- | --- | --- | --- |
| R6, chamber effect | 2.9 % to 5.3 % (63 % baffle) | 1.8 % (same power) to 3.3 % (same speed), target 5 % | Met on paper; TRL 4 comparison runs decide |
| R10, cost | USD 4,920 against USD 1,000 | USD 3,865 against the restated USD 4,000 (USD 135 under) | Met as restated |
| R8, pump-down | 4.0 min with a new 170 L/min pump | Unchanged with a 170 L/min host lab pump; about 4.9 min at 140 L/min | Met if the pump is at least 140 L/min |

Value-engineering target: USD 1,000. Estimated cost of the constructable design: USD 3,865 (USD 2,865 over the target). Mass: about 585 kg with the pump and cabinet in the model; the 80 % baffle is 1.3 kg lighter than the 63 % sheet. (The model had counted the baffle as a solid 7.7 kg disc; it now counts the solid share of the sheet only.)

## Consequences

- Model: `BAF_OPEN` 0.80, `BAF_HOLE` 22, `BAF_PITCH` 24.5 in `cad/src/model.py`, with checks that the open area is at least 80 % and the bars are no thinner than the sheet. STEP and STL regenerated.
- Drawings: ALR-DWG-001 Rev P3 (baffle note); making sketches ALR-DWG-101 Rev P2 (surplus pipe checks), ALR-DWG-110 Rev P2 (surplus head checks), ALR-DWG-115 Rev P2 (80 % sheet).
- The cost now depends on the host lab: a project without a lab supply and pump would pay about USD 535 more (USD 4,400), over the restated R10.

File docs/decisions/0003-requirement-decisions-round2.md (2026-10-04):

---
doc_id: ALR-DDR-003
title: AltiRig requirement decisions, round 2
project: AltiRig
doc_type: Design decision record
version: "0.1"
status: Draft
date: '2026-10-03'
author: Amish Chadha
license: CERN-OHL-S-2.0
revisions:
- version: "0.1"
  date: '2026-10-03'
  author: Amish Chadha
  change: R6 (chamber effect) and R10 (cost) decided by Amish on 2026-10-03, both as recommended
---

# 0003: Requirement decisions, round 2

- **Date:** 2026-10-03
- **Status:** decided. Decided by Amish Chadha, 2026-10-03: "i approve all of the 47 recommendations provided by you. Execute them." Both decisions below were the recommended options in the TRL 3 review note (`docs/REVIEW.md`, Decisions for Amish) and are taken exactly as worded there.

## Context

At TRL 3 two requirements were not met or at risk on paper (ALR-CAL-001 v0.2). R6 (chamber effect) was at risk: the closed loop of air, crossing the 63 % open perforated baffle twice, was estimated to give 2.9 % (same power) to 5.3 % (same speed) more thrust than open air, against a 5 % target. R10 (cost) was not met: USD 4,920 against the USD 1,000 value-engineering target, driven by about 470 kg of vessel steel, USD 650 of welding and about USD 780 for the motor supply, speed controller and safety controls. Each was posed to Amish with three options and a recommendation.

> **Safety:** Neither decision relaxes a safety provision. Second-hand steel is accepted only after the roundness and thickness checks that the shell's collapse factor of 6.7 depends on; a borrowed pump is used only if it has a thermal overload and an exhaust filter; a borrowed supply stays behind the interlocked contactor and the emergency stop.

## Options considered

*Table 1. Options for each decision.*

| Requirement | A | B | C |
| --- | --- | --- | --- |
| R6, chamber effect | Keep the 63 % open baffle: 2.9 % to 5.3 % (at risk), no change to cost or mass | 80 % open perforated or expanded-metal baffle on the same tabs: 1.8 % to 3.3 %, about USD 10 more, about 3 kg less | 1,016 mm (40 in) vessel with the 63 % baffle: 1.1 % to 2.0 %, about USD 900 more, about 150 kg more |
| R10, cost | Keep the parts as specified: USD 4,920 | Surplus pipe offcut and tank heads, the host lab's DC supply and a suitable workshop vacuum pump: about USD 3,700 to 4,000, no mass change, provided the surplus pipe passes the roundness and thickness checks | 610 mm (24 in) vessel for propellers to about 280 mm: about USD 4,200, about 150 kg less, R5 not met and R6 worse |

## Decision

*Table 2. Decisions taken.*

| # | Requirement | Option chosen | Effect | Condition |
| --- | --- | --- | --- | --- |
| 1 | R6, chamber effect | B: an 80 % open perforated or expanded-metal baffle on the same four tabs | Estimated chamber thrust excess 1.8 % (same power) to 3.3 % (same speed), both under the 5 % target: R6 met on paper. Baffle line USD 75 to USD 85. Baffle metal about 1.5 kg against about 2.9 kg for the 63 % plate (1.3 kg less; the option's "about 3 kg" was rounded high). No change to the vessel, the tabs or the clearances | Option C, the 1,016 mm vessel, is held in reserve if the TRL 4 side-by-side comparison still shows more than 5 % |
| 2 | R10, cost | B: surplus pipe offcut and tank heads, the host lab's DC supply and a suitable workshop vacuum pump | Estimated cost USD 3,920 (was USD 4,920; includes the USD 10 baffle increase), still USD 2,920 over the target: R10 still not met. No mass change, no other requirement affected | The surplus pipe passes the roundness (no more than 8 mm between largest and smallest diameter) and thickness (no less than 5.9 mm anywhere) checks, and the heads match the pipe; otherwise new steel is bought (estimate USD 4,390). The supply must give 1,500 W at 20 to 28 V with a remote on/off input, and the pump at least 170 L/min with a thermal overload and an exhaust filter; otherwise they are bought (estimate USD 4,930 with new steel as well) |

## Consequences

- `cad/src/model.py`: `BAF_OPEN` 0.80 and the hole pattern recorded as 10 mm across-flats hexagonal holes on an 11.2 mm pitch. The disc is still drawn solid, so the outer geometry and every clearance are unchanged; its mass now counts only the metal left by the open area (model total 586 kg, was 593 kg because the old disc was counted solid).
- `docs/04-calcs/sizing.py` and `results.csv` (ALR-CAL-001 v0.3): R6 met on paper at 1.8 % to 3.3 %; the 63 % baffle and the reserve 1,016 mm vessel kept as comparison lines; R10 at USD 3,920, with the cost if the conditions fail.
- `bom/bom.csv`: lines 1 (shell, surplus, USD 210 estimate), 3 (heads, surplus, USD 130 each estimate), 17 (baffle, 80 % open, USD 85), 29 (workshop pump borrowed, hose and adapter USD 40 estimate) and 32 (host lab's supply, USD 0). The surplus prices are estimates at about half the new prices in the TRL 3 bill of materials.
- Build plan ALR-BLD-001 v0.2: acceptance checks for the surplus pipe and heads, the new baffle specification, and the specification the borrowed supply and pump must meet.
- Drawings: ALR-DWG-001 to Rev P3 (baffle note); ALR-DWG-115 and the concept blueprint ALR-DWG-010 regenerated with the new text.
- `docs/03-requirements.md` v0.4: R6 and R10 status updated; no target restated.
- This record supersedes the "63 % open" in ALR-DDR-001 D9 and ALR-DDR-002 C8; the rest of those decisions stands.

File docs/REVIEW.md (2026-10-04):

# Review note: AltiRig

## Session 2026-09-30: scaffolded

### What was done

- Repository created from kit 1.6.0 at TRL 1, target TRL 2.
- `docs/01-problem.md` (ALR-PRB-001 v0.1): problem with cited evidence, users, environment, constraints, prior work, open questions.
- `docs/02-concept.md` (ALR-PRC-001 v0.1): how it works, components, patent design-arounds, shared blocks, safety.
- `docs/03-requirements.md` (ALR-REQ-001 v0.1): 10 proposed requirements.
- `README.md` with concept rationale, burning platform, where it could be used, and what sparked the idea.

### Next

- Run `/populate` to bring the repo to a strong TRL 2 with concept media (done 2026-10-03, below).

## Session 2026-10-03: TRL 2 (populate)

Run under Amish's 2026-10-03 instructions: "start with the first 14 repos from the list of 29 projects. I pre-approve the batch runs along with any recommendations you come up with. I also accept any cost overruns or variations from the assumed scope cost." and "Proceed with the remaining 15 scaffolds". Kit updated to 1.7.0.

### What was done

- `docs/01-problem.md` (ALR-PRB-001 v0.2): open questions settled, density target at room temperature explained, co-design candidates and checklist, safety section.
- `docs/03-requirements.md` (ALR-REQ-001 v0.2): concept status for every requirement; R11 (interlocks) and R12 (over-vacuum protection) added.
- `docs/02-concept.md` (ALR-PRC-001 v0.2): how it works, components, key design choices, safety.
- `docs/decisions/0001-trl2-review-decisions.md` (ALR-DDR-001): TRL 2 review decisions D1 to D14.
- Concept media from `cad/src/concept_media.py`: `media/hero.png`, `cutaway.png`, `exploded.png`, `flow.png`, `concept-blueprint.png` and `.pdf` (ALR-DWG-010), `model.glb` (1.3 MB) and `viewer.html`. The media were regenerated from the constructable model at TRL 3.

### Results

- Vessel type chosen: an 813 mm pipe with two 2:1 ellipsoidal tank heads, one as the door; density matched (61.9 kPa at 20 °C for 5,000 m), not pressure.

### Requirements not met

- None decided at TRL 2; R6 and R10 are reported in the TRL 3 section.

### Decisions made under the pre-approval

- D1 to D14 in ALR-DDR-001, including the co-design candidates (IIT Kanpur first, Kathmandu University second; candidates, not agreed) and the conservative safety choices: vessel designed for full vacuum (relax only with a code calculation and a strain-gauged proof test), polycarbonate window outside the fragment zone (relax only with impact tests), no batteries inside (relax only with a vent and fire plan and abuse tests).

### Safety concerns

- Vacuum vessel (implosion, window failure), door held by tonnes of force, spinning propeller, mains power. Safety sections are in every document.

## Session 2026-10-03: TRL 3 (advance and build plan)

### What was done

- `docs/04-calcs/01-sizing.md`, `sizing.py`, `results.csv` (ALR-CAL-001 v0.2): density, vessel strength, pump-down, heating and density control, stand, chamber effect, data, cost; results against every requirement.
- `cad/src/model.py`: parametric build123d model of 48 components with an overlap check (none) and clearances; `cad/step/altirig-assembly.step`, `altirig-vessel.step`, `altirig-stand.step`; `cad/stl/altirig-stand.stl`, `altirig-assembly.stl`.
- `cad/src/sheets.py`: general arrangement ALR-DWG-001 Rev P2.
- `bom/bom.csv`: 38 lines, every line priced with a supplier type.
- `docs/decisions/0002-design-for-construction.md` (ALR-DDR-002): changes C1 to C17.
- `cad/src/build_plan_media.py`: overview, 22 making sketches (ALR-DWG-101 to 122), 10 joint close-ups, 20 step pictures.
- `docs/05-build-plan.md` (ALR-BLD-001) and `docs/06-design-decisions.md` (ALR-DEC-001).
- `cad/src/product_model.py` (hero, exploded, detail) and scenes exported to `/home/claude/renders/altirig` for the photoreal renders on Amish's Mac.
- `docs/02-concept.md` v0.3, `docs/03-requirements.md` v0.3, README, `project.yaml` (trl 3, design_state constructable).

### Results

- Density of 5,000 m: 0.736 kg/m3 at 61.9 kPa (20 °C); relief at 46.3 kPa absolute.
- Vessel at full vacuum: shell collapse factor 6.7, heads 40, window 7.1 on yield; openings 1.7 and 2.3 times the area needed; door held by 24 kN at the 5,000 m point.
- Pump-down to 54 kPa: 4.0 min with a 170 L/min pump; 0.93 m3 free volume.
- Stand: thrust error 0.13 N (0.27 % of 50 N); torque 0.28 % of 2 N m; speed 0.02 %; density error 0.6 %.
- Example 15 x 5 in propeller at 50 N and 5,000 m density: 10,830 rpm, about 1,800 W electrical, so the 1,500 W supply limits it to about 44 N.
- Mass: about 470 kg vessel, about 590 kg with pump and cabinet.
- Value-engineering target: USD 1,000. Estimated cost of the constructable design: USD 4,920 (USD 3,920 over the target).

### Requirements not met

- **R6 (chamber effect): at risk.** Estimated 2.9 % (same power) to 5.3 % (same speed) more thrust in the chamber than in open air with the 63 % open baffle.
- **R10 (cost): not met.** USD 4,920.

### Decisions for Amish

**R6, chamber effect.**

- **State:** the estimate is 2.9 % to 5.3 % above open air at the same speed, against the R6 target. Cause: the perforated baffle, crossed twice by the loop of air inside the closed vessel, adds resistance that slows the propeller's own flow, so it makes more thrust at the same speed.
- **Option A:** keep the 63 % open baffle as designed. Effect on R6: 2.9 % to 5.3 % (at risk). Cost and mass: no change.
- **Option B:** use an 80 % open perforated or expanded-metal baffle, still bolted to the same tabs. Effect on R6: 1.8 % to 3.3 %. Cost: about USD 10 more. Mass: about 3 kg less. It still breaks up the jet and the swirl; the comparison runs at TRL 4 are made with and without it.
- **Option C:** a 1,016 mm (40 in) vessel with the 63 % baffle. Effect on R6: 1.1 % to 2.0 %. Cost: about USD 900 more (pipe, heads, rings, welding). Mass: about 150 kg more.
- **Recommendation: B.** It brings both estimates under the target at almost no cost and keeps the vessel; C is held in reserve if the TRL 4 comparison still shows more than 5 %.

**R10, cost.**

- **State:** USD 4,920 against the USD 1,000 value-engineering target. Cause: a vessel safe at full vacuum needs about 470 kg of pipe, heads and plate and about USD 650 of welding; the 1,500 W motor supply, speed controller and safety controls add about USD 780.
- **Option A:** keep the parts as specified. Cost: USD 4,920. No effect on any other requirement.
- **Option B:** source the pipe offcut and tank heads as surplus, and use the host lab's existing DC supply and a workshop vacuum pump that has a thermal overload and exhaust filter. Cost: about USD 3,700 to 4,000 (saving about USD 900 to 1,200). Mass: no change. Requirements: none affected, provided the surplus pipe meets the roundness and thickness checks in the register.
- **Option C:** a 610 mm (24 in) vessel for propellers up to about 280 mm. Cost: about USD 4,200. Mass: about 150 kg less. R5 would then not be met (380 mm propellers no longer fit), and R6 would worsen with the same propellers.
- **Recommendation: B.** It saves the most without touching what the rig does; the safety checks on second-hand steel are already in the plan.

### Decisions made under the pre-approval

- ALR-DDR-002, design for construction C1 to C17 (listed below and in the register).
- Cost overrun against the value-engineering target accepted; `budget_usd` left at USD 1,000.

### Design changes made for construction (2026-10-03)

- C1 shell from an 813 x 6.35 mm pipe offcut; C2 flat flange rings with a sponge gasket, door held shut by air; C3 heavy-wall set-in nozzles with square-cut ends, no pads; C4 window stack with a spacer ring that sets the gasket squeeze; C5 potted IP68 feed-through plate; C6 welded saddles; C7 deck rails and bolted deck; C8 bolted 63 % baffle on four tabs; C9 hinge with slotted door lugs; C10 three latch clamps; C11 flexure stand with an upright bar cell between anchor and hanger; C12 torque head on two bearings with an arm on a second cell; C13 speed sensor post; C14 manifold on a stub flange; C15 normally-open bleed valve; C16 feed-through on the window side outside the fragment zone; C17 pump and cabinet placement.

### Build plan findings

- Twenty-two made components, ten joints and twenty steps. Every part was checked for overlap with every other (none) in the model.
- The shell's strength depends on the rear head and the flange ring being welded continuously all round (with no end support the factor falls to about 1); the plan makes this a hold point.
- The 80 mm propeller-to-deck clearance and the 15 mm sensor-to-propeller gap are the tightest clearances.
- The door weighs about 72 kg and the shell about 185 kg: the welding steps need a hoist.

### Appearance model deviations (product_model.py)

- The baffle is drawn as a plain disc; its holes are not modelled.
- The control cabinet is left out of the hero render; a 1.75 m mannequin stands beside the door end, not between the camera and the vessel.
- In the exploded render the stand, the deck and the test article are lifted out above the vessel.
- These are appearance choices only and are decided under the pre-approval; no dimension differs from `model.py`.

### Safety concerns

- Implosion or window failure under vacuum: vessel designed for full vacuum, relief valve, polycarbonate only, proof pump-down behind a guard after a qualified engineer's review.
- The door under vacuum carries up to 62 kN at full vacuum: vent before unlatching.
- Propeller failure: window and feed-through outside the 15° fragment zone; steel shell contains fragments; interlocked arming.
- Mains: RCD, earthed vessel, emergency stop, normally-open bleed valve.
- Batteries are excluded from the chamber in this version.

### Recommended next step

- Amish decides R6 and R10 above. Then, for TRL 4 (when the phase cap allows): have the vessel calculation reviewed by a qualified engineer, build the vessel with the co-design partner, proof-test it, and run the R6 comparison with and without the baffle.

## 2026-10-03: photoreal renders

Rendered with Blender Cycles on Amish's Mac from `cad/src/product_model.py`; captioned with `.kit/photo_caption.py`; `media/card.png` and `media/social-preview.png` made with `.kit/cards.py`. Views: hero, exploded, detail. image_qc passes and `render.py --check` has no FAIL.

## 2026-10-03: Amish's requirement decisions carried out

Amish, 2026-10-03: "i agree with all the 46 recommendations you provided. please proceed." For AltiRig these are decisions 41B (R6) and 42B (R10), each as recommended in the TRL 3 section above. Recorded in `docs/decisions/0003-requirement-decisions.md` (ALR-DDR-003) and the register `docs/06-design-decisions.md` v0.2. Not committed or pushed (batch run).

### Changes

- **41B, R6.** The baffle (BOM line 17) is now 2 mm perforated steel with 22 mm square holes on a 24.5 mm square pitch: 80.6 % open, 2.5 mm bars, the same 790 mm disc on the same four tabs. About 1.5 kg; USD 85 (USD 10 more; price basis: the 63 % sheet's USD 75 plus a less common square-hole pattern). The 1,016 mm vessel is held in reserve if the TRL 4 comparison runs show more than 5 %.
- **42B, R10.** Shell (line 1) a surplus offcut, USD 150 (was 420; about 185 kg at about USD 0.80 a kg). Heads (line 3) second-hand or overstock, USD 130 each (was 260; about half the new price). Vacuum pump (line 29) from the host lab: only the hose, clamps and adapter are bought, USD 45 (was 260). Motor DC supply (line 32) from the host lab, USD 0 (was 320), still switched through the cabinet's interlocked contactor and emergency stop. R10 restated in `docs/03-requirements.md` v0.4 as "complete rig at or below USD 4,000, built with a surplus pipe offcut and tank heads that pass the roundness and thickness checks, and the host lab's existing DC supply and vacuum pump; the USD 1,000 value-engineering target is kept as a control figure".
- **Model.** `cad/src/model.py`: `BAF_OPEN` 0.80, `BAF_HOLE` 22, `BAF_PITCH` 24.5, new `baffle_open()`; new checks that the open area is at least 80 % and the bars are no thinner than the sheet; the baffle's mass now counts only the solid share of the sheet (it had been counted as a solid 7.7 kg disc). Checks: no overlaps, both new checks pass. STEP and STL regenerated.
- **Calculations.** `docs/04-calcs/sizing.py` and `01-sizing.md` v0.3: section F with the 80 % baffle as designed (superseded 63 % case and the 1,016 mm reserve kept for comparison), section H with the restated R10 and a cost-change table with a price basis per line; `results.csv` re-run.
- **Pictures.** General arrangement ALR-DWG-001 Rev P3 (baffle note 80 % open). Making sketches ALR-DWG-101 Rev P2 (surplus pipe checks before buying), ALR-DWG-110 Rev P2 (surplus head checks), ALR-DWG-115 Rev P2 (80 % square-hole sheet). Concept blueprint key figures (chamber effect and cost) and the concept media regenerated (`model.glb` is now 3.9 MB, was 1.3 MB, at the required glTF deflections). The overview, joint 7 and Step 12 are unchanged: the model draws the baffle as a plain disc, so they look the same.
- **Text.** `docs/05-build-plan.md` v0.2 (summary, 3.1 shell, 3.15 baffle, 3.23 bought components with the host lab's pump and supply, Step 20), `docs/02-concept.md` v0.4, `README.md`, `project.yaml` (budget comment, trl_evidence).
- **Appearance model.** `cad/src/product_model.py` now cuts the baffle's square holes (inside an 8 mm rim, clear of the bolt holes) so the exploded render shows the open sheet; scenes re-exported to `/home/claude/renders/altirig`. This replaces the earlier plain-disc deviation.

### New results (ALR-CAL-001 v0.3)

- R6: met on paper. 1.8 % (same power) to 3.3 % (same speed) more thrust than open air, against 5 % (was 2.9 % to 5.3 %). Baffle removed: 1.4 % to 2.5 %. The TRL 4 comparison runs with and without the baffle decide it.
- R10: met as restated. USD 3,865 against USD 4,000 (USD 135 under). Value-engineering target: USD 1,000. Estimated cost of the constructable design: USD 3,865 (USD 2,865 over the target). `budget_usd` unchanged.
- R8: unchanged at 4.0 min with a 170 L/min host lab pump; a pump rated 140 L/min gives about 4.9 min, so the host lab's pump must be at least 140 L/min.
- Mass: about 585 kg with the pump and cabinet (model); the 80 % baffle is 1.3 kg lighter than the 63 % sheet.
- All twelve requirements are now met on paper.

### For Amish

- No new decision. The cost now depends on the host lab: without its pump and supply the rig costs about USD 4,400, over the restated R10. What the lab's pump and supply must meet is in the register's To confirm list (rows 6 and 9).
- The photoreal renders (`media/render-*.png`), card and social preview still show the plain baffle disc; re-render on the Mac from the re-exported scenes.

### Cross-repo actions

- None. Neither decision touches another repo.

### Safety

- No change to the vessel or its safety case. Surplus pipe and heads are accepted only after the roundness and thickness checks that the shell's collapse factor of 6.7 assumes; the build plan and making sketches now put these checks before purchase.
- The host lab's DC supply is never wired straight to the speed controller: it is switched by the cabinet's interlocked contactor and emergency stop (R11). The host lab's pump must have a thermal overload and an oil-mist filter, exhausting outdoors.
- The 80 % baffle carries no pressure; its rim is filed smooth to remove sharp part-holes.

## 2026-10-04: photoreal renders redone after the round-2 and round-3 decisions

Views: hero, exploded, detail; cards regenerated; image_qc passes and `render.py --check` has no FAIL.

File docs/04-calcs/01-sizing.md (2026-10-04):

---
doc_id: ALR-CAL-001
title: AltiRig sizing calculations
project: AltiRig
doc_type: Calculation
version: "0.3"
status: Draft
date: '2026-10-03'
author: Amish Chadha
license: CERN-OHL-S-2.0
revisions:
- version: "0.1"
  date: '2026-10-03'
  author: Amish Chadha
  change: First sizing of the TRL 3 concept against every requirement
- version: "0.2"
  date: '2026-10-03'
  author: Amish Chadha
  change: Re-run for the constructable design (ALR-DDR-002), with heavy-wall set-in nozzles, flexure stand, 63 % open baffle and bill of materials cost
- version: "0.3"
  date: '2026-10-03'
  author: Amish Chadha
  change: "Amish's decisions 41B and 42B (ALR-DDR-003): 80 % open baffle (R6 now 1.8 % to 3.3 %, met on paper); surplus pipe and heads with the host lab's DC supply and pump (USD 3,865); R10 restated"
---

# AltiRig sizing calculations

On paper the constructable design meets all twelve requirements, R10 as restated by Amish on 2026-10-03. The vessel is designed for full vacuum with a collapse factor of 6.7 on the shell, the stand measures 0 to 50 N within 0.27 % of full scale, and a 170 L/min pump reaches 54 kPa in about 4 minutes. With the 80 % open baffle (decision 41B) the closed loop of air is estimated to raise thrust by 1.8 % to 3.3 %, inside the 5 % of R6. With a surplus pipe and heads and the host lab's DC supply and vacuum pump (decision 42B) the estimated cost is USD 3,865, under the restated R10 limit of USD 4,000. Amish, 2026-10-03: "i agree with all the 46 recommendations you provided. please proceed."

> **Safety:** These are hand calculations for a concept on paper, made to choose sizes. They are not a pressure vessel design to any code and do not make the vessel safe to use. A qualified engineer reviews section B before any pump-down, and the first pump-down is a proof test behind a guard (ALR-BLD-001, section 6).

## Scope and method

`docs/04-calcs/sizing.py` makes every calculation and writes `docs/04-calcs/results.csv`. Dimensions come from the model (`cad/src/model.py`) and prices from `bom/bom.csv`, so a change to either is carried through by running the script again. Sections A to H follow the requirements; section I lists every result against every requirement.

## Assumptions

1. International Standard Atmosphere for altitude conditions; dry air, R = 287.05 J/(kg K).
2. Steel to S235 or A36 class: modulus 200 GPa, minimum yield 235 MPa. Polycarbonate: modulus 2.3 GPa, yield 62 MPa.
3. The vessel is designed for full vacuum (101.3 kPa difference), not only for the working point, because the pump can pull close to full vacuum if the relief valve sticks.
4. Shell buckling by the Windenburg and Trilling formula with a knock-down of 0.5 for out-of-roundness up to 1 % of the diameter and weld distortion. Heads treated as spheres of radius 0.9 D with a knock-down of 0.25 on the classical value.
5. Plastic windows: at least 6 on yield at full vacuum, simply supported at the gasket's outer edge.
6. Pump speed 85 % of the 170 L/min rating between 50 and 100 kPa, after the hose and the filter.
7. Example propeller 15 x 5 in, static thrust coefficient 0.10 and power coefficient 0.042 (typical of the UIUC static data for two-blade propellers of this pitch ratio); measured values replace them at TRL 4.
8. Heat transfer from the moving air to the steel wall 30 W/(m2 K); air temperature spread in the chamber plus or minus 1.5 K.
9. Chamber effect: actuator-disc momentum balance with the loop losses added (section F). Two blade models bracket the answer: the same shaft power, and the same speed with thrust falling linearly to zero at the pitch speed.

## A. Density targets (R1, R12)

The chamber matches density, not pressure. Room-temperature air reaches the density of 5,000 m at a higher pressure than the 54.0 kPa of 5,000 m, because the real air there is at -17.5 °C.

*Table 1. Density targets.*

| Quantity | Value |
| --- | --- |
| Standard atmosphere at 5,000 m | 54.0 kPa, -17.5 °C, 0.736 kg/m3 (60 % of sea level) |
| Standard atmosphere at 6,000 m | 0.660 kg/m3 |
| Chamber pressure for 0.736 kg/m3 at 15, 20, 25 and 30 °C | 60.9, 61.9, 63.0 and 64.1 kPa |
| Density at 54.0 kPa and 20 °C | 0.642 kg/m3, about the density of 6,100 m |
| Lowest working pressure needed (6,000 m density at 30 °C) | 57.4 kPa |
| Pressure difference at the R1 point (0.736 kg/m3, 20 °C) | 39.4 kPa |
| Relief valve: lowest chamber pressure | 46.3 kPa (55.0 kPa below atmosphere) |
| Design pressure difference for the vessel | 101.3 kPa (full vacuum) |

R1 is met: the pump reaches far below 61.9 kPa. R12 sets the relief valve below every working point, with a margin of 11 kPa under the lowest one.

## B. Vessel strength (R7, R11)

*Table 2. Vessel strength at full vacuum.*

| Part | Result | Factor |
| --- | --- | --- |
| Shell, 813 x 6.35 mm, unsupported length 1,718 mm | Elastic buckling 1,351 kPa; with the 0.5 knock-down 676 kPa; plastic limit 3,671 kPa | 6.7 on collapse (R7 target at least 4) |
| Shell, if the ends gave no support at all | Long-cylinder bound 209 kPa, halved | 1.0, so the flange ring and the head must stay welded all round |
| Heads, 2:1 ellipsoidal, 6.35 mm | Equivalent sphere 732 mm radius | 40 on collapse |
| Window opening (10 in XS set-in nozzle, 12.7 mm wall) | Area to replace 641 mm2 | 1.7 times the area needed, no pad |
| Feed-through opening (6 in XS set-in nozzle, 10.97 mm wall) | Area to replace 379 mm2 | 2.3 times the area needed, no pad |
| Window, polycarbonate 20 mm, span 165 mm radius | Bending stress 8.7 MPa; centre deflection 2.6 mm | 7.1 on yield (rule at least 6) |
| Feed-through plate, aluminium 15 mm | Bending stress 3.9 MPa | over 60 on yield |

The door is held shut by the air. Inside the gasket line the door area is 0.615 m2, so at the R1 point the door carries 24.2 kN (about 2.5 t) and at full vacuum 62.3 kN. Even 2 kPa of vacuum holds it with 1.2 kN, so nobody can open it until the chamber has been vented (R11). At full vacuum the sponge gasket carries 0.5 MPa and closes fully; the flange rings then bear on it. For the first seal the three latches pull the door 25 % into the sponge with about 6.3 kN, 2.1 kN each, against a rating of at least 3 kN. The 72 kg door hangs on the hinge with a horizontal force of 0.92 kN at each lug pair; stresses in the 20 mm pin and 15 mm lugs stay under 10 MPa.

## C. Volume and pump-down (R8, R11)

The free volume inside the vessel is 0.928 m3. With 144.5 L/min of effective pump speed, an isothermal pump-down takes 4.0 minutes to 54.0 kPa (R8, target 5 minutes) and 3.2 minutes to the R1 point. A leak of 0.2 L/min of free air is allowed for; at 54 kPa it raises the pressure by about 0.3 kPa a minute, which the controller makes up. Venting through the 6 mm bleed orifice from 54 kPa to ambient takes about 130 s, so the door cannot be opened in a rush after a run.

## D. Air heating and density control (R2)

All the electrical power put into the motor ends as heat inside the vessel. At 1,500 W the air settles about 9.5 K above the wall within a few seconds (time constant 4.4 s) and the 470 kg of steel warms by only 0.4 K a minute. To hold density, the controller raises the pressure by up to 3.2 % as the air warms, by opening the bleed valve.

*Table 3. Density error budget.*

| Source | Error |
| --- | --- |
| Pressure sensor, 50 Pa absolute | 0.08 % |
| Temperature probe, class A, 0.15 K | 0.05 % |
| Spread of air temperature in the chamber, 1.5 K | 0.51 % |
| Humidity correction | 0.07 % |
| Control band of the bleed loop | 0.30 % |
| Root sum square | 0.60 % (R2 target 1 %) |

## E. Propeller loads and the thrust stand (R3, R4, R5, R11)

*Table 4. Example propeller at 50 N (15 x 5 in, assumed coefficients).*

| Condition | Speed | Shaft power | Torque | Tip speed |
| --- | --- | --- | --- | --- |
| Sea level, 20 °C | 8,470 rpm | 1,126 W | 1.27 N m | 169 m/s |
| 5,000 m density | 10,830 rpm | 1,440 W | 1.27 N m | 216 m/s |

At 5,000 m density 50 N takes about 1,800 W of electrical power, more than the 1,500 W supply; with this propeller the supply allows about 44 N. The stand itself reads to 50 N; a larger supply is only needed for the heaviest propellers. The blade Reynolds number at three quarters of the radius falls from about 179,000 to 109,000 at 6,000 rpm, which is why sea-level data cannot simply be scaled.

The thrust stand is a parallelogram of two 0.5 mm spring-steel leaves, so it has no sliding friction. The leaves together are 11.7 N/mm stiff, carry 2.9 % of the thrust in parallel with the load cell (a fixed share, removed by calibration through the same path), move 0.12 mm at 50 N and are stressed to 5.8 MPa. Their buckling load is 17 times the 4.7 kg they carry. The 9.3 N m pitching moment from thrust acting above the cell is taken as tension and compression in the leaves.

*Table 5. Measurement error budgets.*

| Quantity | Budget | Result |
| --- | --- | --- |
| Thrust (R3) | Cell 0.05 % of 98 N, cable drag 0.1 N, zero drift, masses, flexure 0.1 % | 0.13 N, 0.27 % of 50 N (target 1 %) |
| Torque (R4) | Cell on a 60 mm arm (33 N at 2 N m on a 49 N cell), bearing friction 0.001 N m, cable drag 0.005 N m | 0.006 N m, 0.28 % of 2 N m (target 2 %) |
| Speed (R4) | Optical sensor, blade pass at up to 367 Hz, 1 microsecond timer | 0.02 % per revolution (target 0.5 %) |

Clearances (R5): the tip of a 380 mm propeller is 210 mm from the shell and 80 mm above the deck. The window's nearest edge is 18.3° from the propeller plane and the feed-through's 20.9°, both outside the 15° zone in which a broken blade's fragments travel (R11). A half blade of 25 g released at 50 N and 5,000 m density carries about 210 J, which the 6.35 mm steel shell contains.

## F. Chamber effect (R6)

The propeller drives a loop of air inside the vessel: down the middle, through the baffle, round the rear head and back along the wall. In open air the jet's kinetic energy is lost far downstream; in the chamber the same energy is lost where the jet mixes at the baffle, so to first order the propeller sees the same flow. What is added are the loop's own losses: the baffle, crossed twice, and the two 180° turns.

*Table 6. Chamber effect estimates at 50 N, ambient pressure.*

| Case | Extra loop loss (dynamic heads at the disc) | Thrust excess, same power | Thrust excess, same speed |
| --- | --- | --- | --- |
| As designed: 813 mm vessel, 80 % open baffle (decision 41B) | 0.22 | 1.8 % | 3.3 % |
| Baffle removed | 0.17 | 1.4 % | 2.5 % |
| Superseded: 63 % open baffle (TRL 3 design before decision 41B) | 0.36 | 2.9 % | 5.3 % |
| Reserve: 1,016 mm vessel with the 80 % baffle | about 0.08 | 0.7 % | 1.2 % |

The baffle is 2 mm steel sheet with 22 mm square holes on a 24.5 mm square pitch, so (22/24.5) squared gives 80.6 % open; its loss coefficient falls from 1.85 to 0.54 dynamic heads at the section velocity. The disc covers 23 % of the chamber section (inside diameter 2.1 times the propeller), and the return flow runs along the wall at about 3.9 m/s at 50 N. The same-speed model is the one that matters for R6, which compares thrust at the same speed. R6 is met on paper: 3.3 % against the 5 % target, a margin of 1.7 points. The inflow is less even than in open air, which these models do not capture, so the side-by-side runs at TRL 4, with and without the baffle, decide it. If they show more than 5 %, the 1,016 mm vessel is the reserve option (Amish's decision 41B keeps it in reserve).

## G. Data (R9)

The controller logs density, thrust, torque, speed, voltage and current to CSV at 20 Hz; the load-cell amplifiers sample at 80 Hz. R9 is met by design.

## H. Mass and cost (R10)

The vessel with its door, saddles and fittings is about 470 kg of steel; the whole rig with the pump and the control cabinet is about 585 kg (model masses). The 80 % baffle weighs about 1.5 kg, 1.3 kg less than the 63 % sheet (the model now counts only the solid share of the perforated sheet; before, it counted the baffle as a solid 7.7 kg disc). Decision 42B changes where parts come from, not what they are, so no other mass changes.

Value-engineering target: USD 1,000. Estimated cost of the constructable design: USD 3,865 (USD 2,865 over the target). R10, restated by Amish on 2026-10-03 (decision 42B), limits the rig to USD 4,000 built with a surplus pipe offcut and tank heads and the host lab's DC supply and vacuum pump: USD 3,865 is USD 135 under it.

*Table 6a. Cost changes from decisions 41B and 42B.*

| BOM line | Before | After | Price basis |
| --- | --- | --- | --- |
| 1 Shell | USD 420 (new-cut) | USD 150 (surplus offcut) | About 185 kg at about USD 0.80 a kg, surplus line-pipe remnant |
| 3 Dished heads (2) | USD 520 | USD 260 | About half the new price, second-hand or overstock heads |
| 17 Baffle plate | USD 75 (63 % open) | USD 85 (80 % open) | Less common square-hole pattern, about USD 10 more |
| 29 Vacuum pump and hose | USD 260 | USD 45 (hose, clamps, adapter) | Host lab's pump; hose about USD 12 a metre |
| 32 Motor power supply | USD 320 | USD 0 | Host lab's DC supply |
| Total | USD 4,920 | USD 3,865 | |

The largest items are now the welding labour (USD 650), the flange rings, saddles, nozzles and window rings (about USD 820), the valve manifold (USD 220), and the speed controller and safety controls (USD 280). The surplus pipe and heads are accepted only after the checks in the design decisions register: out-of-roundness no more than 8 mm, wall no less than 5.9 mm anywhere, head diameter, thickness and skirt matched to the pipe. The host lab's pump needs a rating of at least about 140 L/min (5 CFM) of free air to keep the pump-down within R8's 5 minutes (pump-down time scales inversely with pump speed: 4.0 min x 170 / 140 is about 4.9 min; section C), and its DC supply needs at least 1,500 W at 24 V, or the thrust reached at 5,000 m density falls below about 44 N (section E). Both are checked before the host lab's equipment is accepted.

## I. Results against every requirement

*Table 7. Results against every requirement.*

| ID | Result | Status |
| --- | --- | --- |
| R1 | 0.736 kg/m3 at 61.9 kPa and 20 °C; pump reaches far lower | Met |
| R2 | Density error 0.60 % | Met |
| R3 | 0 to 50 N, error 0.27 % of full scale | Met |
| R4 | Torque error 0.28 % of 2 N m; speed 0.02 % | Met |
| R5 | 380 mm propeller with 210 mm to the wall, 80 mm to the deck | Met |
| R6 | Thrust 1.8 % to 3.3 % high with the 80 % open baffle | Met (decision 41B) |
| R7 | Collapse factor 6.7 at full vacuum (shell); heads 40; window 7.1 on yield | Met |
| R8 | 4.0 min to 54 kPa | Met |
| R9 | 20 Hz CSV | Met |
| R10 | USD 3,865 against the restated USD 4,000 (value-engineering target USD 1,000, USD 2,865 over) | Met as restated (decision 42B) |
| R11 | Door held by 24 kN under vacuum; key, latch interlock and emergency stop; vent in about 130 s; window and feed-through outside the fragment zone | Met by design |
| R12 | Relief at 46.3 kPa; vessel designed for full vacuum | Met |

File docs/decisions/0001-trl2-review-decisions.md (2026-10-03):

---
doc_id: ALR-DDR-001
title: AltiRig TRL 2 review decisions
project: AltiRig
doc_type: Design decision record
version: "0.1"
status: Draft
date: '2026-10-03'
author: Amish Chadha
license: CERN-OHL-S-2.0
revisions:
- version: "0.1"
  date: '2026-10-03'
  author: Amish Chadha
  change: TRL 2 review decisions D1 to D14, decided under Amish's 2026-10-03 pre-approvals
---

# 0001: TRL 2 review decisions

- **Date:** 2026-10-03
- **Status:** decided. Amish, 2026-10-03: "start with the first 14 repos from the list of 29 projects. I pre-approve the batch runs along with any recommendations you come up with. I also accept any cost overruns or variations from the assumed scope cost." And for this second batch, Amish, 2026-10-03: "Proceed with the remaining 15 scaffolds". Each decision below is the recommendation made at the TRL 2 review and is decided as recommended. Requirements that are not met or at risk are not decided here; they are posed to Amish in `docs/REVIEW.md` and the design decisions register.

## Context

The scaffold (ALR-PRC-001 v0.1) described a sealed vessel with a thrust stand inside and left open the vessel type, whether to chill the air, how to deal with the propeller's recirculating wake, and whether a propeller and motor kit belongs in this repo. The TRL 2 review settled these so the TRL 3 calculations (ALR-CAL-001), the model and the build plan could proceed. Choices that touch safety take the conservative option, and each says what evidence would relax it.

> **Safety:** AltiRig is a vacuum vessel with a spinning propeller inside, run from mains power. These decisions set the design basis on paper only. Nothing here makes the chamber safe to use; it is not certified pressure equipment or test equipment.

## Decisions

*Table 1. TRL 2 review decisions.*

| # | Decision | Reason | Affects |
| --- | --- | --- | --- |
| D1 | Match air density, not pressure: R1's 0.74 kg/m3 is reached at about 61.9 kPa at 20 °C; pressure and temperature are logged with every point | Thrust and power scale with density; at room temperature, 54 kPa would give the density of about 6,100 m | R1; controller; ALR-CAL-001 A |
| D2 | Vessel: a horizontal 813 mm (32 in) x 6.35 mm steel pipe offcut, 1,500 mm long, with two bought 2:1 ellipsoidal tank heads; one head welded on the rear, one on a flange ring as the door | A thin steel drum collapses at a few kPa of vacuum; a flat-panelled box needs heavy ribs; pipe and tank heads are stocked items a welding shop can join | Vessel parts; R5, R7; cost |
| D3 | Design the vessel for full vacuum (101.3 kPa difference) and apply R7's factor of 4 at full vacuum, not only at the working point | Conservative: the pump can reach near full vacuum if the relief valve sticks. Relax only with a code calculation by a qualified engineer and a strain-gauged proof test | R7; ALR-CAL-001 B |
| D4 | Add R12: an adjustable vacuum relief valve opens at 55 kPa below atmosphere, so the chamber cannot go below 46.3 kPa absolute in normal use | Covers every working point (lowest 57.4 kPa) with margin and limits the load on the window and the door | R12; valve manifold |
| D5 | Add R11: the motor can be armed only with the door latched (interlock switch) and the key turned; the emergency stop removes motor and pump power; the bleed valve is normally open, so the chamber vents on loss of power | The door is held shut by air under vacuum, so the hazard is a running propeller when the door is open or a run that cannot be stopped | R11; cabinet; build plan safety stops |
| D6 | Window: clear polycarbonate 20 mm, never acrylic or glass, placed with its nearest edge more than 15° from the propeller plane | Polycarbonate yields rather than shatters; keeping it out of the fragment zone protects the one non-steel wall. Relax only with impact tests of the window at TRL 4 | Window; R7, R11 |
| D7 | Thrust stand: two spring-steel flexure leaves (no rails), a 10 kg bending-beam cell for thrust, a torque head on two bearings with an arm on a 5 kg cell, an optical speed sensor | No sliding friction; bought C3 cells; the share carried by the leaves is fixed and calibrated out | R3, R4; stand parts |
| D8 | Room temperature only in the first version; chilling towards -20 °C is a later variant | Density, not temperature, sets thrust; chilling a 0.9 m3 vessel adds a refrigeration plant and condensation | Scope; R1 |
| D9 | Closed chamber with a removable 63 % open perforated baffle, and side-by-side comparison runs at ambient pressure published with every data set | The scaffold's open question on recirculation; the baffle breaks up the jet and swirl, and the comparison runs measure what the loop does. Whether R6 is met is posed to Amish separately | R6; baffle; ALR-CAL-001 F |
| D10 | No lithium or sodium-ion battery inside the chamber in the first version; the motor is powered from a 1,500 W supply outside through the feed-through | Conservative: a battery fire in a closed vessel raises the pressure and fills it with toxic fumes. Relax only with a vent, a fire-containment plan and abuse tests of the pack type | Scope; ColdCell; feed-through |
| D11 | Co-design: the first candidate partner to approach is the Department of Aerospace Engineering, IIT Kanpur; the second is the Department of Mechanical Engineering, Kathmandu University. First candidate region: the Nepal and Indian Himalaya. Recorded as candidates, not agreed | Propeller facilities and Himalayan users; a partner reviews the vessel calculation and runs the open-air comparison | ALR-PRB-001 co-design |
| D12 | The high-altitude propeller, motor and tuning kit is not part of this repo; AltiRig publishes measured data and the Kitewright Lift and Range frames publish their kits from it | Keeps AltiRig a test rig and the kits with the aircraft they serve | Scope; shared blocks |
| D13 | Shared blocks: CalRig's proof-load method calibrates the load cells; ColdCell packs are not tested inside the chamber in this version (D10) | Re-use across the portfolio without adding a battery hazard | ALR-PRC-001 shared blocks |
| D14 | Publish as an open engineering reference with a notice that it is not certified pressure or test equipment; before any use a qualified engineer reviews the vessel calculation and the first pump-down is a proof test behind a guard | Conservative; follows the safety notes in the scaffold | README and every document; build plan safety stops |

## Consequences

- R11 and R12 are added to ALR-REQ-001.
- The vessel, welding, motor supply and safety controls take the estimated cost well above the USD 1,000 value-engineering target (ALR-DEC-001, Value engineering). Amish accepted cost overruns in the same instruction; R10 is posed to Amish with options in `docs/REVIEW.md`.

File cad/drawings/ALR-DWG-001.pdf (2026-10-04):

CONCEPT, NOT FOR FABRICATION | AltiRig · github.com/BoujeeEnjinia1701/altirig

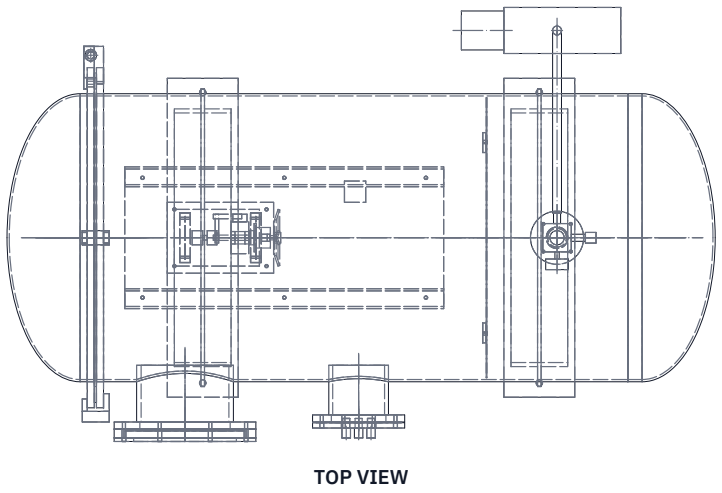
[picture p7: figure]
TOP VIEW
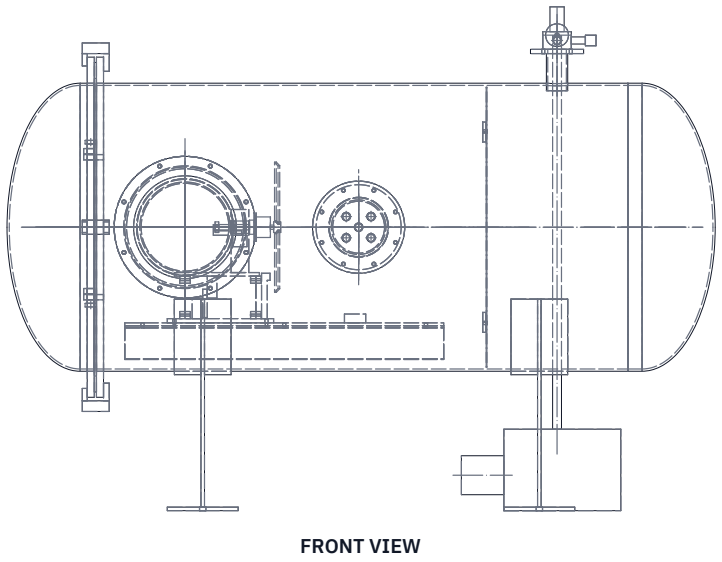
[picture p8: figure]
FRONT VIEW

Scale 1:20; looking at the front (along +Y)

Scale 1:20; looking down (along -Z)

RIGHT VIEW
Scale 1:20; looking at the right side (along -X)

1999

1225 1422

ISOMETRIC VIEW
Not to scale; control cabinet not shown; seen from the front right and above, about 30 deg elevation

MAIN DIMENSIONS AND INTERFACES (MM)
Shell (1): pipe 813 OD x 6.35 wall, 1500 long; axis 800 above floor Heads (3): 2:1 ellipsoidal, 813 OD; rear welded, door on a flange ring Flange rings (2): 960 OD x 813 ID x 20; gasket 6 sponge
Window (13): polycarbonate 340 dia x 20, centre 250 from flange face Window nozzle (4): 273.1 x 12.7; feed-through (5): 168.3 x 10.97 Propeller plane 510 from flange face; up to 380 dia
Baffle (17): 790 dia, 80 % open, 1100 from flange face
Deck (16) top 530 above floor; saddles (7) at 300 and 1250
Vessel designed for full vacuum; relief valve opens at 55 kPa below atmosphere Hinge (10) on the far side; door swings open to +Y
Third-angle; top view from +Z; (n) = BOM line
REV | DESCRIPTION | DATE | BY
P1 | General arrangement of the TRL 3 concept | 2026-10-03 | AC
P2 | Constructable design (ALR-DDR-002) | 2026-10-03 | AC
P3 | 80 % open baffle (decision 41B) | 2026-10-03 | AC
ALTIRIG | github.com/BoujeeEnjinia1701/altirig

## Altitude test chamber with a thrust stand: general arrangement

DRAWING NO.
ALR-DWG-001

REV
P3

SHEET
1 of 1

SIZE

## ANSI B

SCALE
1:20

UNITS
mm
PROJECTION | DATE
2026-10-03

DRAWN
Amish Chadha

MATERIAL / NOTES
Per bom/bom.csv: carbon steel vessel (pipe, plate, tank heads), polycarbonate window, 6082 aluminium stand. PRELIMINARY, NOT FOR FABRICATION
Licensed CERN-OHL-S-2.0 · Design Molecule Lab · designmolecule.com | Generated from cad/src; do not edit by hand

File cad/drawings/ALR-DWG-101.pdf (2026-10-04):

### BUILD PLAN SKETCH, PLAN NOT YET BUILT AltiRig · github.com/BoujeeEnjinia1701/altirig

FRONT VIEW
Scale 1:20; looking at the front (along +Y)

TOP VIEW
Scale 1:20; looking down (along -Z)

RIGHT VIEW
Scale 1:20; looking at the right side (along -X)

1500

813 813

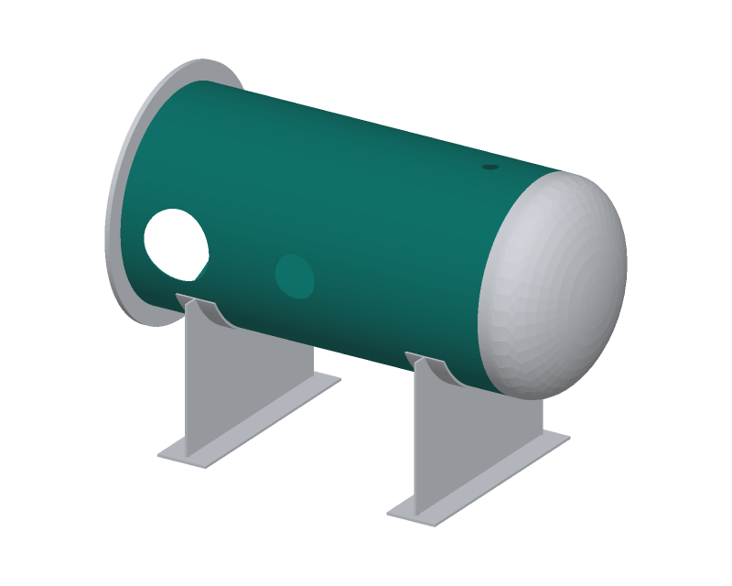
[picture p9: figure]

WHERE IT GOES
This part in colour, its neighbours in grey

HOW TO MAKE IT AND HOW IT FITS
Surplus offcut: before buying, check it is round within 8 mm (largest less smallest diameter) and the wall is 5.9 or more at 8 points round each end; reject a dented or pitted pipe
Cut the pipe 1,500 long, ends square within 1 mm
Mark a line along the top; hole centres measured from the door end: window hole 273.1 dia at 250, on the side 90 deg from the top feed-through hole 168.3 dia at 740, same side as the window manifold hole 60.3 dia at 1300, on the top line
Cut each hole to the nozzle's outside size plus 1 to 2 mm, square to
the axis; grind smooth; bevel the outside edge for the fillet weld Saddles, rails, tabs, ring and head are welded on (assembly steps 1 to 5) Check: holes on the right side and line; nozzle stubs slide in
REV | DESCRIPTION | DATE | BY
P1 | Making sketch | 2026-10-03 | AC
P2 | Surplus pipe checks before buying (decision 42B) | 2026-10-03 | AC
ALTIRIG | github.com/BoujeeEnjinia1701/altirig

## AltiRig shell: pipe offcut with nozzle holes

DRAWING NO.
ALR-DWG-101

REV
P2

SHEET
1 of 1

SIZE

## ANSI B

SCALE
1:20

UNITS
mm
PROJECTION | DATE
2026-10-03

DRAWN
Amish Chadha

MATERIAL / NOTES
Steel pipe 813 OD x 6.35 wall (32 in x 1/4 in), 1,500 long
Licensed CERN-OHL-S-2.0 · Design Molecule Lab · designmolecule.com | Generated from cad/src; do not edit by hand

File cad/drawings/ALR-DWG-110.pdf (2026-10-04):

### BUILD PLAN SKETCH, PLAN NOT YET BUILT AltiRig · github.com/BoujeeEnjinia1701/altirig

FRONT VIEW
Scale 1:20; looking at the front (along +Y)

TOP VIEW
Scale 1:20; looking down (along -Z)

RIGHT VIEW
Scale 1:20; looking at the right side (along -X)

246

1020 960

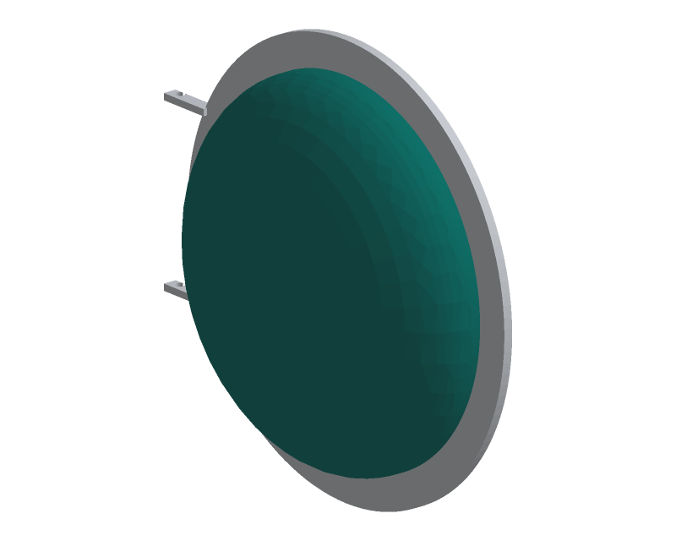
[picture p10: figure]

WHERE IT GOES
This part in colour, its neighbours in grey

HOW TO MAKE IT AND HOW IT FITS
The door is the second tank head with the second flange ring Surplus heads: 813 OD, wall 5.9 or more, 40 mm skirt; check before buying that the skirt fits the ring and the pipe
Set the ring over the head's 40 mm skirt, face flush with the skirt's open end; check the face is flat within 1 mm
Fillet weld ring to skirt both sides in short balanced runs Weld the two door lugs to the ring's edge (sheet 109)
Grind the gasket face smooth where the welds meet it
The door weighs about 72 kg: lift it with a hoist or two people Check: door face flat; no weld proud of the face
REV | DESCRIPTION | DATE | BY
P1 | Making sketch | 2026-10-03 | AC
P2 | Surplus head checks before buying (decision 42B) | 2026-10-03 | AC
ALTIRIG | github.com/BoujeeEnjinia1701/altirig

## AltiRig door: head welded into a flange ring

DRAWING NO.
ALR-DWG-110

REV
P2

SHEET
1 of 1

SIZE

## ANSI B

SCALE
1:20

UNITS
mm
PROJECTION | DATE
2026-10-03

DRAWN
Amish Chadha

MATERIAL / NOTES
Bought 813 OD 2:1 head, 6.35; door flange ring (sheet 102)
Licensed CERN-OHL-S-2.0 · Design Molecule Lab · designmolecule.com | Generated from cad/src; do not edit by hand

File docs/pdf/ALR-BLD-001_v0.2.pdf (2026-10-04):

A LT I R I G · B U I L D P L A N

# AltiRig prototype build plan

Design Molecule Lab · designmolecule.com

D O C U M E N T CO N T RO L

Document ID | ALR-BLD-001 | Version | 0.2
Status | Draft | Date | 2026-10-03
Author | Amish Chadha | License | CERN-OHL-S-2.0
Project TRL | TRL 3 | Proof of concept
Repository | github.com/BoujeeEnjinia1701/altirig
Source | docs/05-build-plan.md @ uncommitted

R EV I S I O N H I STO RY

Version | Date | Author | Change
0.2 | 2026-10-03 | Amish Chadha | Amish's decisions 41B (80 % open baffle) and 42B (surplus pipe and heads, host lab's DC supply and pump), ALR-DDR-003
0.1 | 2026-10-03 | Amish Chadha | First build plan; design made constructable (ALR-DDR-002)

D R A F T · N O T F O R F A B R I C A T I O N

## AltiRig prototype build plan

Plan, not yet built. How to build the first proof-of-concept AltiRig, component by component. Building and testing to it is TRL 4 work. Decisions still to be made are kept in the design decisions register ( docs/06-design-decisions.md ), not here.

Safety: AltiRig is a vacuum vessel with a spinning propeller inside, run from mains power. At the 5,000 m point the air presses on the vessel with 39 kPa and holds the door shut with about 24 kN (2.5 t). A collapsed vessel or a failed window can throw fragments, and a propeller can break at speed. Welding on the vessel is done by a qualified welder. Nothing is pumped down until a qualified engineer has reviewed the vessel calculation (ALR-CAL-001, section B), and the first pump-down is a proof test behind a guard (section 6). No battery goes inside the chamber. This is a prototype for testing, not certified pressure or test equipment.

### 1. What you are building

Figure 1. Every component pulled apart and numbered in build order: the vessel 1 to 18, window and feed-through 19 to 24, valve manifold, baffle and deck 25 to 27, the thrust stand 28 to 43, the motor and propeller under test 44 and 45, and the pump, hose and control cabinet 46 to 48.
The prototype is a horizontal steel vacuum vessel about 2 m long and 813 mm in diameter, standing on two saddles with its axis 800 mm above the floor, with a flexure thrust stand inside. The vessel is a length of steel pipe with a bought dished head welded on the rear end; the door is a second head welded into a flange ring, hung on a hinge and pulled onto a sponge gasket by three latches. A polycarbonate window and a cable feed-through plate sit on short pipe nozzles on the near side, and a valve manifold sits on top. Inside, a deck carries the stand: a base plate, two spring-steel leaves holding a carriage, a load cell for thrust, a torque head on bearings with a second load cell, and a speed sensor. Twenty-two kinds of part are made, in a welding shop and a small machine shop: cutting pipe and plate, drilling and tapping, rolling one strip, welding, boring and turning. The valves, gaskets, load cells, electronics and test article are bought. The pipe and the two heads are bought surplus, and the host lab lends its DC power supply and vacuum pump (Amish's decision 42B). The parts cost about USD 3,865 from the bill of materials.

### 2. What changed to make it buildable

The TRL 2 concept named the parts but not how they are made or held. Each change keeps what the chamber does; all are recorded in decision record ALR-DDR-002.
Table 1. Changes from the concept.
Component | The concept had | The buildable design has | Why
Shell | "A steel drum or tank" | An 813 x 6.35 mm pipe offcut with holes cut to the nozzle sizes | Stocked, round enough for the buckling calculation
Door seal | A door with no detail | Two flat 20 mm rings, one on the shell and one on the door head, with a sponge gasket between (Figure 26) | No machining; the sponge takes up weld distortion; vacuum closes the joint
Nozzles | A window and feed- throughs in the wall | Heavy-wall stubs set in through the wall and cut square, welded inside and out (Figures 28 and 29) | No contour cutting; the heavy wall replaces the steel removed, so no pads
Window | "A polycarbonate or laminated window" | 20 mm polycarbonate clamped over a spacer ring that sets the gasket squeeze (Figure 28) | Never over-clamped; no holes in the window
Feed-through | "Sealed connectors" | An aluminium plate with five potted IP68 cable glands (Figure 29) | Stock parts; potting stops leaks along the strands
Saddles, deck, baffle | Not shown | Welded saddles; two angles inside with a bolted deck; a bolted perforated baffle on four tabs (Figures 31, 32 and 35) | Something to stand on, build on and take out
Hinge and latches | Not shown | Lugs and a pin on the far side; three bolt-on latches (Figure 30) | Carry the 72 kg door and pull it on for the first seal
Thrust stand | "Load cells" | Two spring-steel leaves carrying a carriage; an upright bar cell between an anchor and a hanger (Figure 33) | No friction; a bending-beam cell is loaded across its length
Torque | "Reaction torque" | A torque head on two bearings, with an arm resting on a second cell (Figure 34) | Reads torque without thrust passing through it
Bleed valve | Any bleed valve | A normally-open valve | The chamber vents when power is lost

### 3. Making the components

Sizes are in millimetres. "Door end" is the end with the door; distances along the vessel are measured from the face of the shell's flange ring. The window side is the near side in the pictures.

### 3.1 Shell

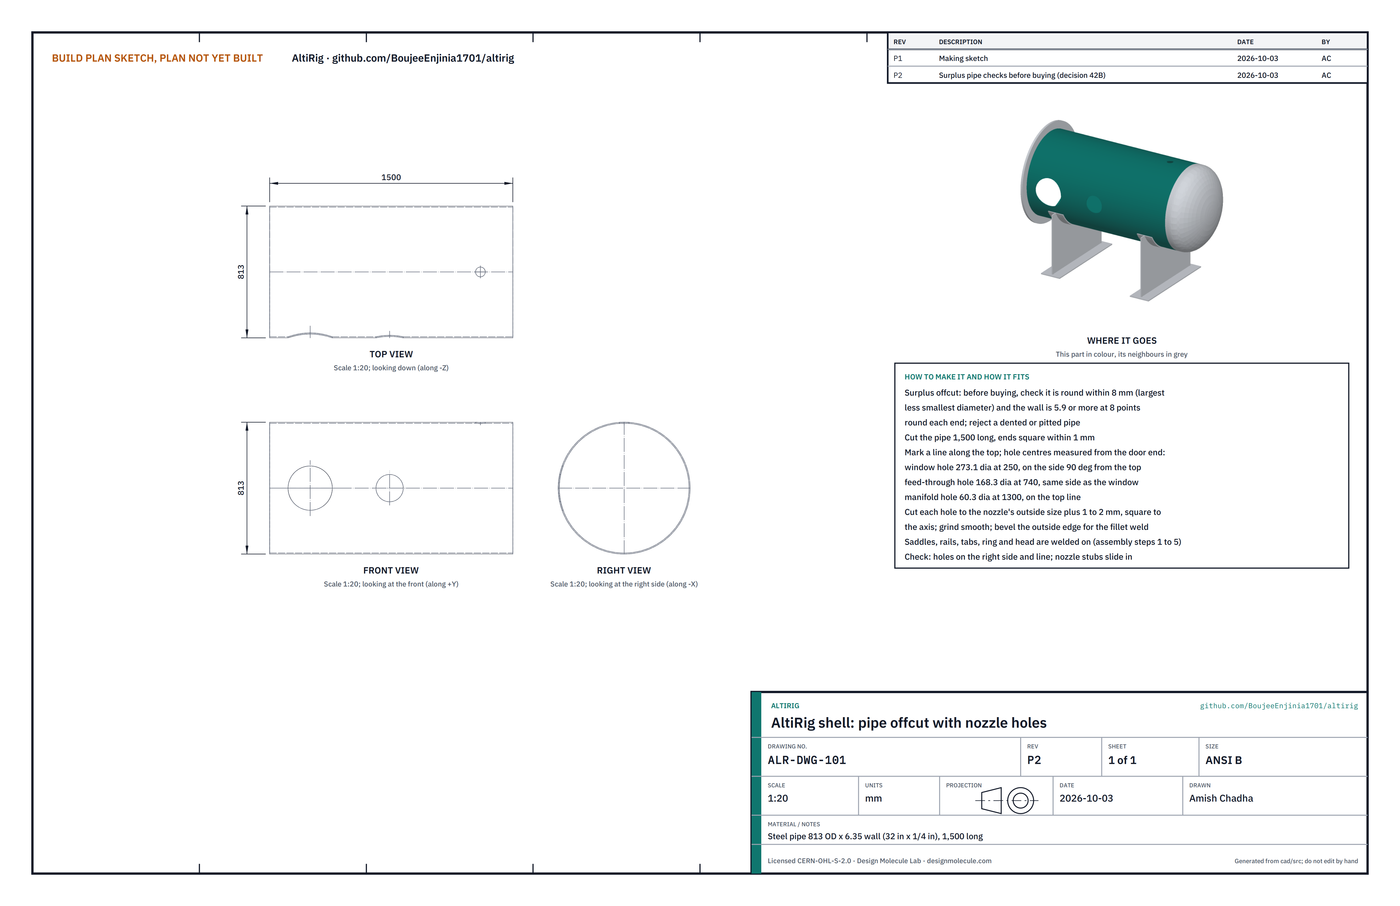
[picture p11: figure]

Figure 2. Shell (ALR-DWG-101).
What it is and what it is made from. The body of the vessel: steel pipe 813 mm outside diameter with a 6.35 mm wall (32 in x 1/4 in), welded line pipe or water pipe, 1,500 mm long. About 185 kg. It is bought as a surplus offcut or remnant from a pipe yard.
How to make it.
Before buying, check the surplus pipe. Measure the diameter at three places around each end and in the middle: the largest less the smallest must be no more than 8 mm. Measure the wall at eight points around each end with a caliper or an ultrasonic gauge: it must be 5.9 mm or more everywhere. Reject a dented or deeply pitted pipe. The vessel's strength depends on both checks.
Cut the pipe 1,500 mm long with both ends square to within 1 mm.
Mark a straight line along the top. Mark the window hole centre 250 mm from the door end and the feed-through hole centre 740 mm from the door end, both on the side, a quarter turn from the top line. Mark the manifold hole 1,300 mm from the door end on the top line.
Cut the holes to the nozzle outside sizes plus 1 to 2 mm: 275 mm for the window, 170 mm for the feed-through, 62 mm for the manifold. Cut square to the pipe's axis. Grind smooth and bevel the outside edge.

1.

2.
3.

4.

How it fits the parts next to it. The flange ring slides over the door end, the rear head butts against the far end, the nozzles pass through the holes, and the saddles' wear plates take it from below. All are welded (steps 1 to 5). Check before moving on. Holes on the right side and the right line; each nozzle stub slides in.

### 3.2 Flange rings (make 2)

Figure 3. Flange rings (ALR-DWG-102).
What it is and what it is made from. Two identical rings of 20 mm steel plate (S275 or A36), 960 mm outside, 813 mm inside. One goes on the shell's door end, one on the door head. The door seals between their faces.
How to make it.
Cut both rings by plasma or waterjet.
Mark the gasket face on each ring and keep it clean of spatter.
Check that each ring slides over the pipe end and over the door head's skirt with a close fit.

How it fits the parts next to it. The shell ring slides over the pipe until its gasket face is flush with the pipe end and is fillet welded on both sides (6 mm leg). The door ring goes over the door head's 40 mm skirt the same way. Weld in short runs at opposite points to keep the faces flat.

1.
2.
3.

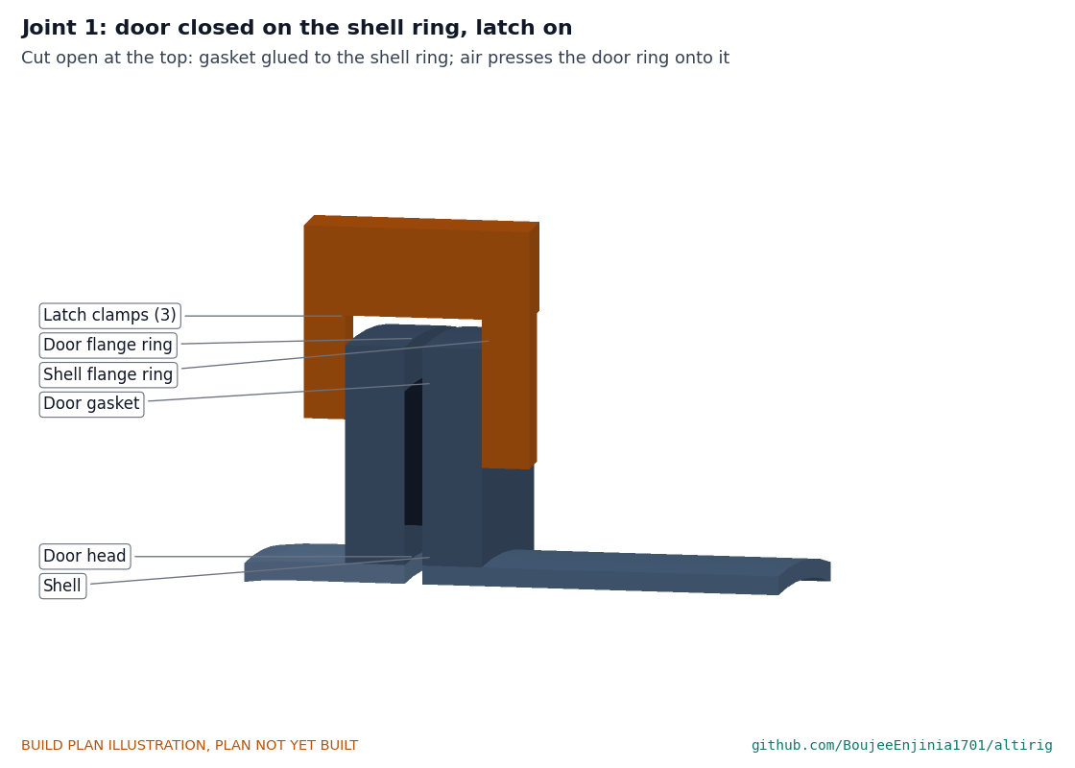
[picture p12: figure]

Figure 26. Joint 1: the door ring against the gasket on the shell ring, with a latch over both rings.
Check before moving on. After welding, each gasket face is flat to within 1 mm under a straight edge.

### 3.3 Window nozzle and flange

Figure 4. Window nozzle and flange (ALR-DWG-103).
What it is and what it is made from. A 160 mm stub of 273.1 mm pipe with a 12.7 mm wall (10 in XS) and a 20 mm steel ring, 400 mm outside and 255 mm inside.
How to make it.
Cut the stub 160 mm long, both ends square.
Cut the ring. Drill and tap eight M10 holes 25 mm deep on a 373 mm circle, the first 22.5° off the top.
Weld the ring onto one end of the stub, face square to the stub.

How it fits the parts next to it. The stub goes through the shell's window hole until the ring face is 520 mm from the vessel's axis; its inner end is then 360 mm from the axis and stands 16 to 40 mm proud of the inner wall. It is fillet welded to the shell outside and inside (8 mm leg). The window stack bolts to the ring (Figure 28).
Check before moving on. Ring face flat to 0.5 mm and square to the stub.

1.
2.
3.

### 3.4 Feed-through nozzle and flange

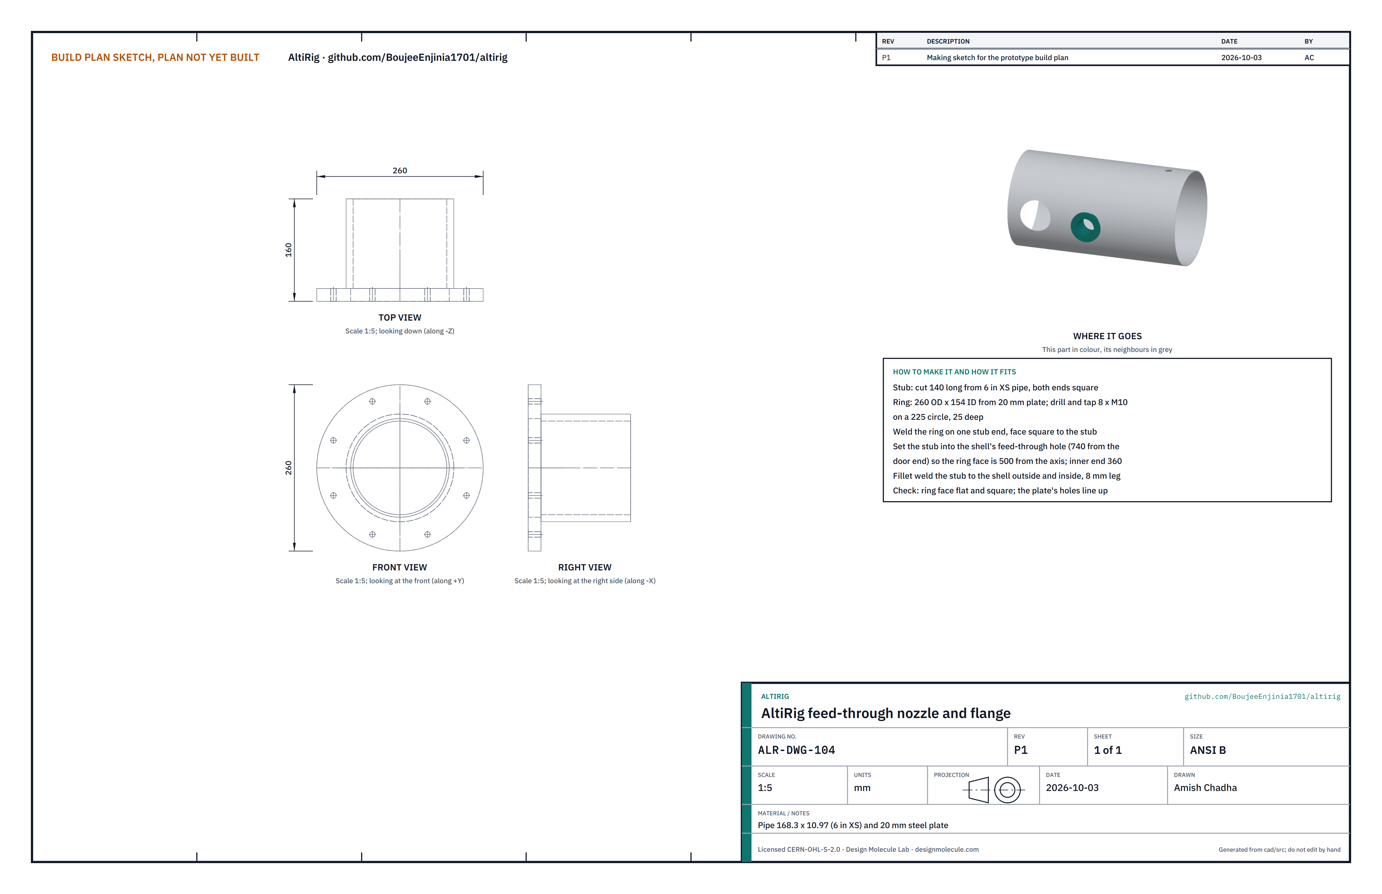
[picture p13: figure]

Figure 5. Feed-through nozzle and flange (ALR-DWG-104).
What it is and what it is made from. A 140 mm stub of 168.3 mm pipe with a 10.97 mm wall (6 in XS) and a 20 mm ring, 260 mm outside and 154 mm inside, with eight M10 tapped holes on a 225 mm circle.
How to make it. As the window nozzle: cut the stub square, cut and tap the ring, weld the ring on square.
How it fits the parts next to it. Set into the feed-through hole until the ring face is 500 mm from the axis; inner end 360 mm from the axis. Welded inside and out. The feed-through plate bolts to the ring (Figure 29).
Check before moving on. Ring face flat and square; the plate's holes line up with the tapped holes.

### 3.5 Manifold stub and flange

Figure 6. Manifold stub and flange (ALR-DWG-105).
What it is and what it is made from. A 105 mm stub of 60.3 mm pipe (2 in schedule 40) with a 150 mm disc of 12 mm plate on top, bored 52.5 mm and tapped for four M8 screws on a 110 mm circle.
How to make it. Cut the stub, cut and bore the disc, tap it, weld it to the stub flush with the bore.
How it fits the parts next to it. The stub goes into the top hole with the disc level, its top face 1,302 mm above the floor, and is fillet welded all round (5 mm leg). The valve manifold bolts on top (Figure 27).
Check before moving on. Disc level to within 1°.

### 3.6 Saddles (make 2)

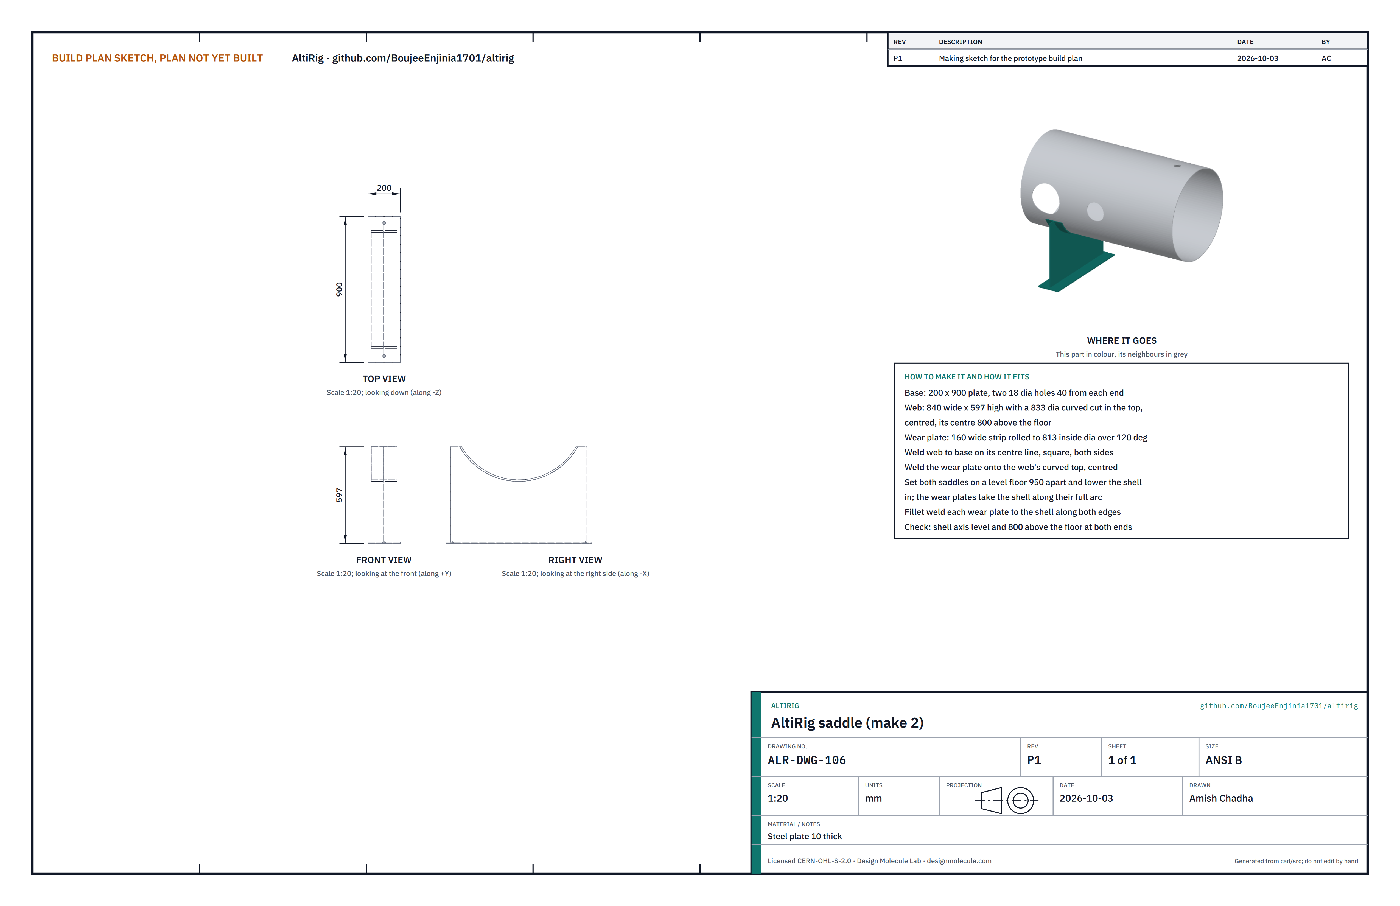
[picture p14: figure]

Figure 7. Saddle (ALR-DWG-106).
What it is and what it is made from. A welded support of 10 mm plate: a 200 x 900 mm base plate, an 840 mm wide web 597 mm high with a curved top, and a 160 mm wear plate rolled to the shell's outside diameter over 120°. About 55 kg each.
How to make it.
Cut the base plate and drill two 18 mm holes 40 mm from each end.
Cut the web with an 833 mm curve in its top, the curve's centre 800 mm above the bottom of the base plate. Roll the wear plate to 813 mm inside diameter.
Weld the web upright on the base's centre line, then the wear plate onto the web's curved top.

How it fits the parts next to it. The shell rests in the wear plates, which are welded to it along both edges (Figure 36). The base plates are bolted to the floor.

1.
2.
3.
4.

Figure 36. Joint 10: the wear plate on the web's curved top, welded to the shell.
Check before moving on. With both saddles on a level floor 950 mm apart, the shell's axis is level and 800 mm above the floor.

### 3.7 Deck rails (make 2)

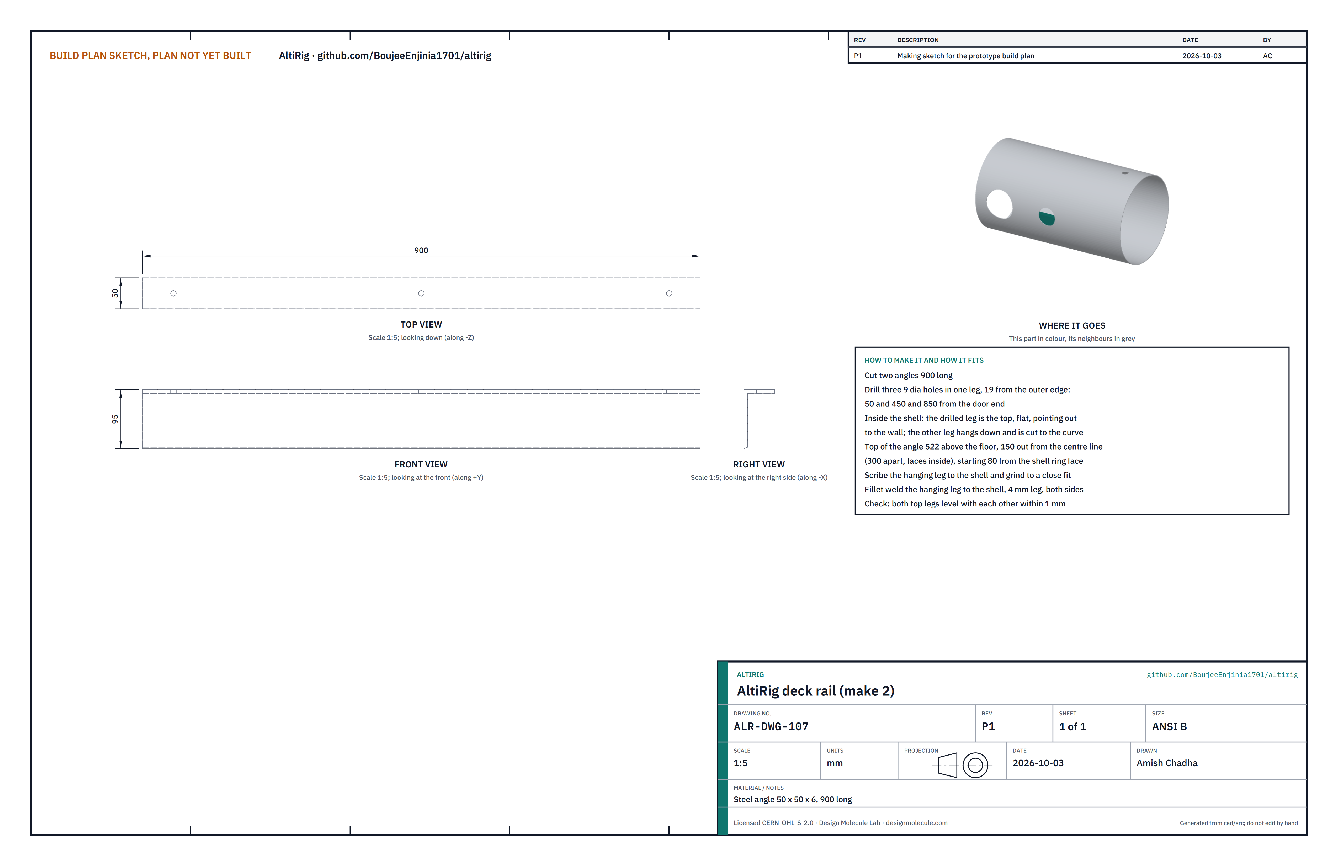
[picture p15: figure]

Figure 8. Deck rail (ALR-DWG-107).
What it is and what it is made from. Steel angle 50 x 50 x 6 mm, 900 mm long.
How to make it. Cut to length. Drill three 9 mm holes in one leg, 19 mm from its outer edge, at 50, 450 and 850 mm from the door end. Scribe the other leg to the inside of the shell and grind to a close fit.
How it fits the parts next to it. Inside the shell, the drilled leg is the top, flat and pointing out toward the wall, 522 mm above the floor; the hanging leg sits on the wall, 150 mm out from the centre line, so the rails are 300 mm apart. They start 80 mm from the shell ring face and are fillet welded along the hanging leg (Figure 32). The deck bolts on top.

Figure 32. Joint 6: the rails welded inside the shell and the deck bolted to their top legs. Check before moving on. Both top legs level with each other to within 1 mm.

### 3.8 Baffle tabs (make 4)

Figure 9. Baffle tabs (ALR-DWG-108).
What it is and what it is made from. Four pieces of 40 x 10 mm steel flat, 45 mm long, each with one 9 mm hole 18 mm from its inner end.
How to make it. Cut, drill and scribe the outer end of each to the shell's curve.
How it fits the parts next to it. Welded inside the shell 1,100 mm from the shell ring face, standing toward the axis, at 45°, 135°, 225° and 315° from the top. The baffle bolts to their door-side faces (Figure 35).
Check before moving on. The four bolt faces lie in one plane to within 2 mm.

### 3.9 Hinge lugs and pin

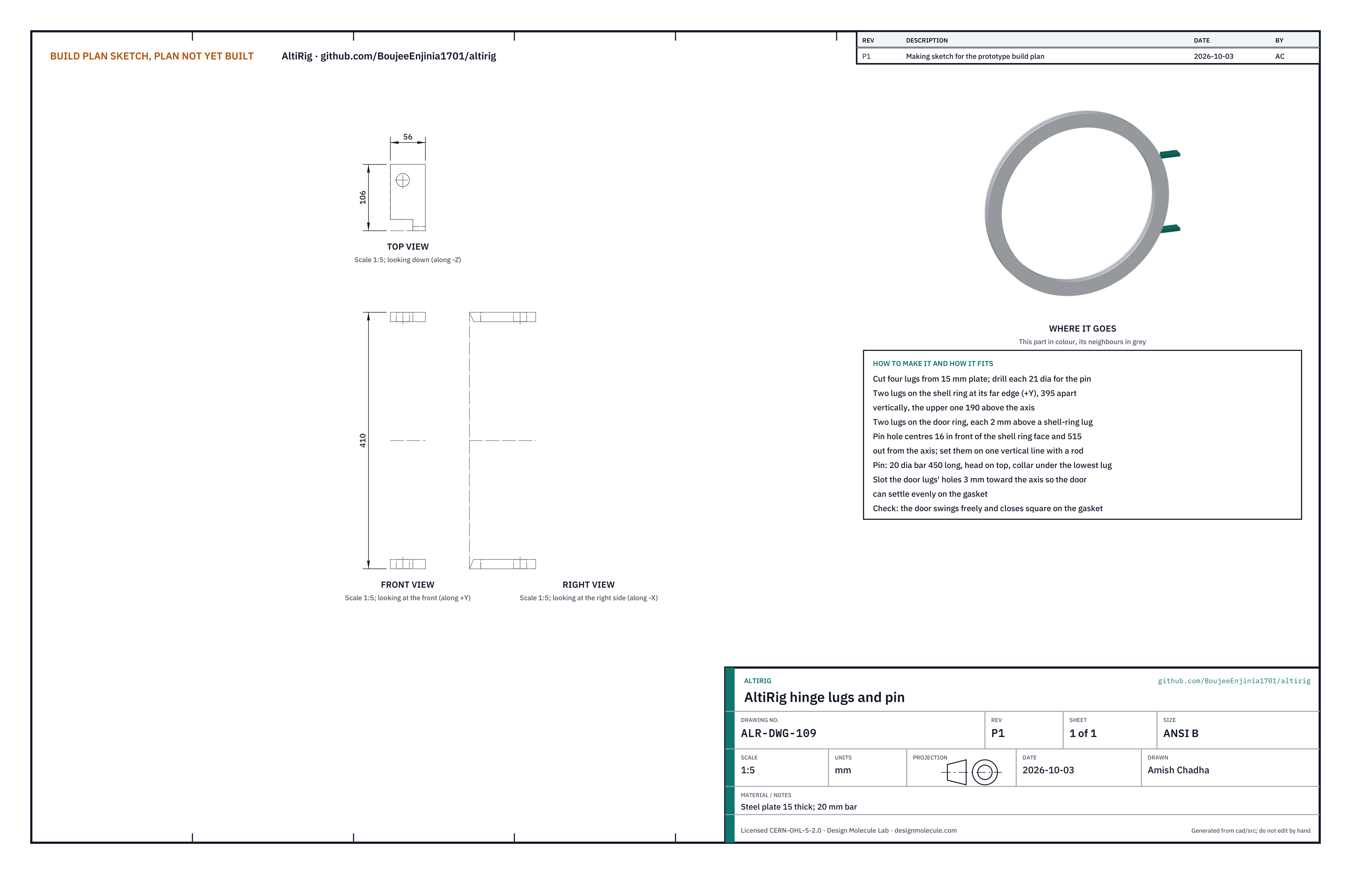
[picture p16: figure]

Figure 10. Hinge lugs and pin (ALR-DWG-109).
What it is and what it is made from. Four lugs of 15 mm steel plate, each with a 21 mm hole, and a 20 mm steel pin 450 mm long with a head and a collar.
How to make it.
Cut the four lugs and drill the holes. Slot the two door lugs' holes 3 mm toward the vessel's axis.
Weld two lugs to the shell ring's far edge, 395 mm apart vertically, the upper one 190 mm above the axis. Weld two lugs to the door ring's far edge, each 2 mm above a shell-ring lug.
Set all four holes on one vertical line with a rod before the welds cool.

How it fits the parts next to it. The pin drops through all four lugs from above; the hole centres are 16 mm in front of the shell ring face and 515 mm out from the axis (Figure 30).

1.
2.
3.
4.

Figure 30. Joint 5: the lugs on both rings and the pin.
Check before moving on. The door swings freely and closes square on the gasket.

### 3.10 Door

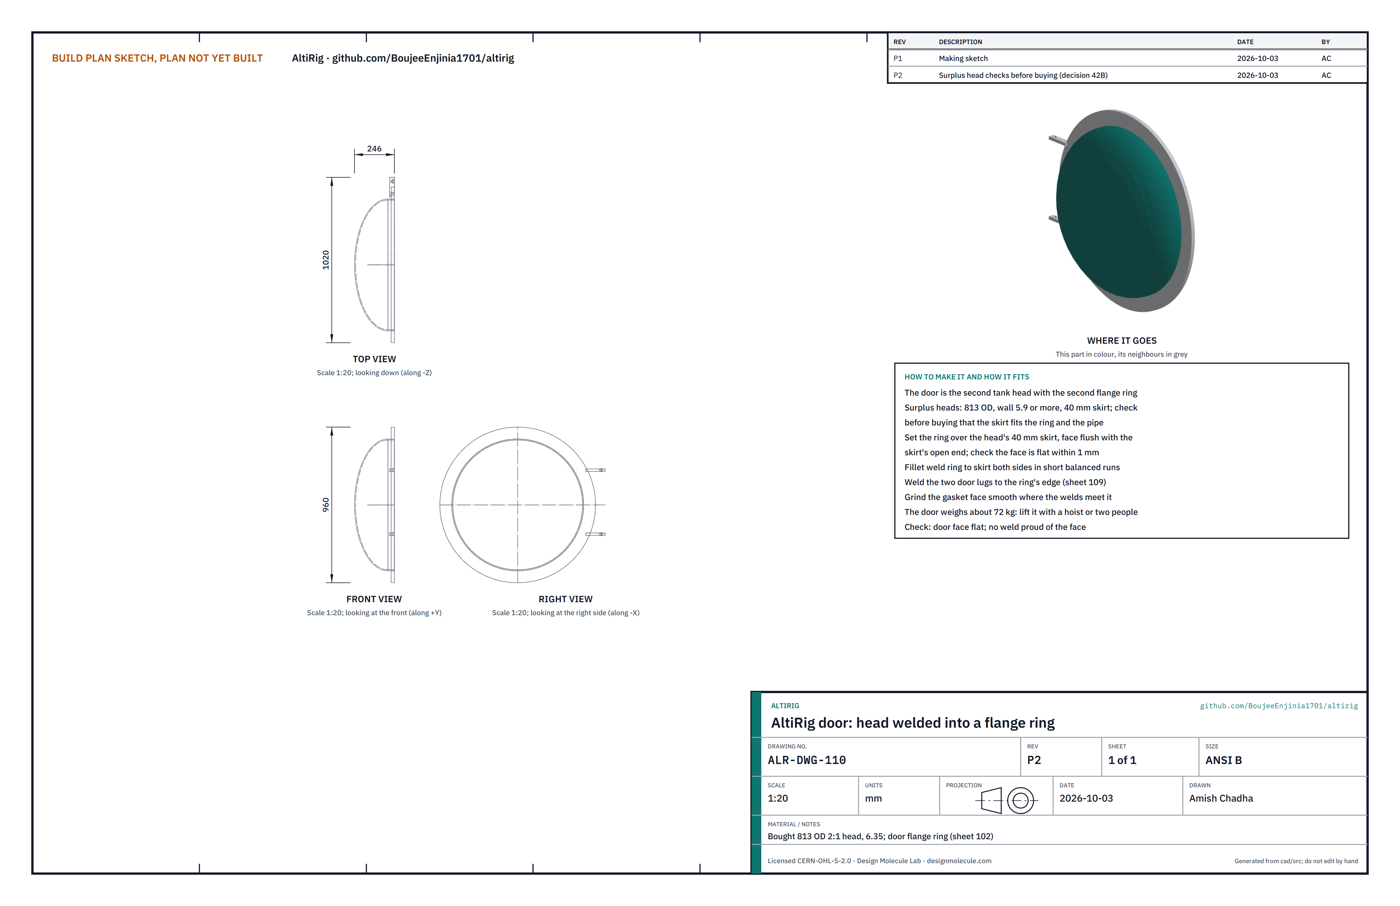
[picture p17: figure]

Figure 11. Door: the second head welded into the second flange ring (ALR-DWG-110).
What it is and what it is made from. A bought 2:1 ellipsoidal tank head, 813 mm outside diameter, 6.35 mm, with a 40 mm straight skirt, welded into the second flange ring, with the two door lugs. About 72 kg.
How to make it.
Set the ring over the head's skirt with its gasket face flush with the skirt's open end.
Fillet weld both sides in short balanced runs.
Grind the gasket face smooth where the welds meet it.

How it fits the parts next to it. The door hangs on the hinge and closes onto the gasket on the shell ring; three latches hold it for the first seal (Figure 26).
Check before moving on. Gasket face flat; no weld proud of it. Lift the door only with a hoist or two people.

1.
2.
3.

### 3.11 Window

Figure 12. Window (ALR-DWG-111).
What it is and what it is made from. A 340 mm disc of clear polycarbonate sheet, 20 mm thick. Never acrylic or glass: they shatter.
How to make it. Cut the disc, sand the edge smooth and break it with a 1 mm chamfer. No holes. Leave the protective film on until fitted. Clean only with water and mild soap; solvents craze polycarbonate.
How it fits the parts next to it. It sits on a 6 mm EPDM ring gasket on the window flange and is held at its rim by the clamp ring (Figure 28). Under vacuum the air presses it onto the gasket.

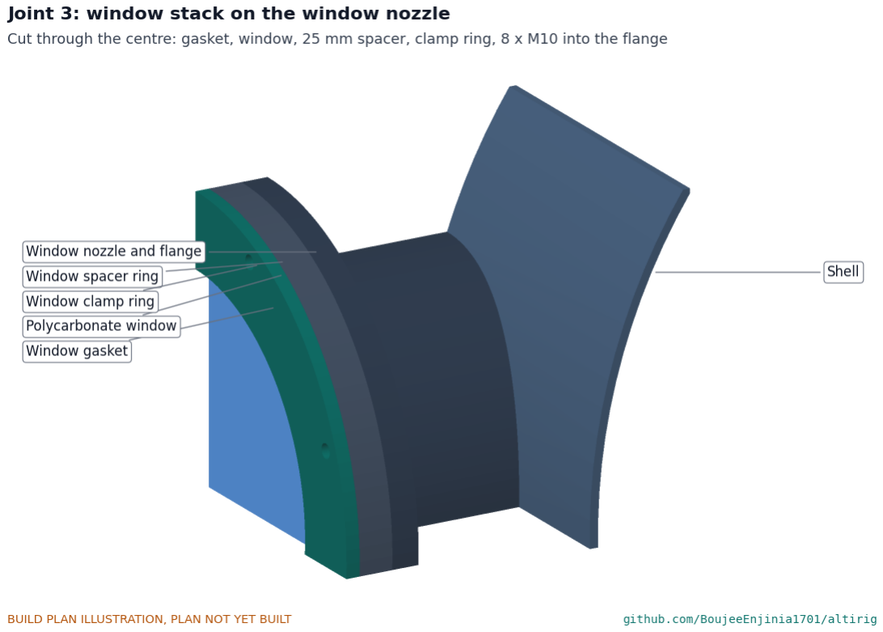
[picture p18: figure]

Figure 28. Joint 3: flange, gasket, window, spacer ring and clamp ring, cut through the window's centre. Check before moving on. No scratch deep enough to catch a fingernail.

### 3.12 Window spacer and clamp rings

Figure 13. Window spacer and clamp rings (ALR-DWG-112).
What it is and what it is made from. A spacer ring of 25 mm plate, 400 mm outside and 346 mm inside, and a clamp ring of 10 mm plate, 400 mm outside and 290 mm inside.
How to make it. Cut both rings. Clamp them together and drill eight 11 mm holes on a 373 mm circle, the first 22.5° off the top, to match the flange. Deburr and paint, except the clamp ring's face that touches the window.
How it fits the parts next to it. The spacer sits on the flange outside the gasket and the window. It is as thick as the gasket squeezed to 5 mm plus the window, so tightening the clamp ring squeezes the gasket by 1 mm and no more. The clamp ring overlaps the window's rim by 25 mm.
Check before moving on. The rings sit flat together and the holes line up with the flange.

### 3.13 Feed-through plate

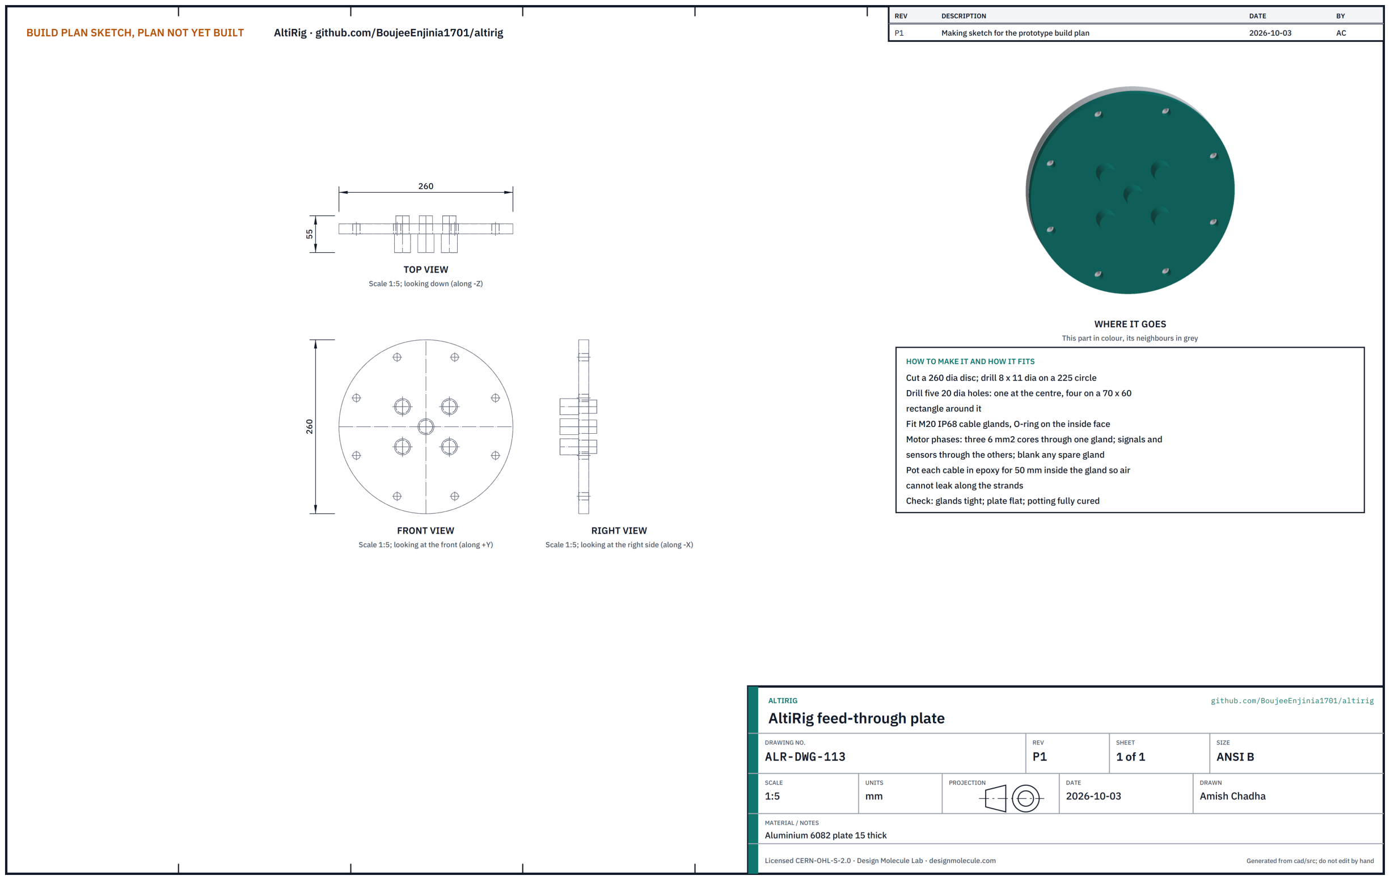
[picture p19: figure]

Figure 14. Feed-through plate (ALR-DWG-113).
What it is and what it is made from. A 260 mm disc of 15 mm aluminium plate with five M20 IP68 cable glands. How to make it.
Cut the disc and drill eight 11 mm holes on a 225 mm circle.
Drill five 20 mm holes: one at the centre and four on a 70 x 60 mm rectangle around it.
Fit the glands with their O-rings on the inside face. Run the three motor phase wires (6 mm2) through one gland and the signal and sensor cables through the others; blank any spare gland.
Pot each cable in epoxy for 50 mm inside its gland so air cannot leak along the strands.

How it fits the parts next to it. It bolts to the feed-through flange with eight M10 bolts on a 2 mm EPDM gasket (Figure 29).

1.
2.
3.

4.

Figure 29. Joint 4: the plate on its gasket and flange, cut through the centre. Check before moving on. Glands tight; potting fully cured.

### 3.14 Deck plate

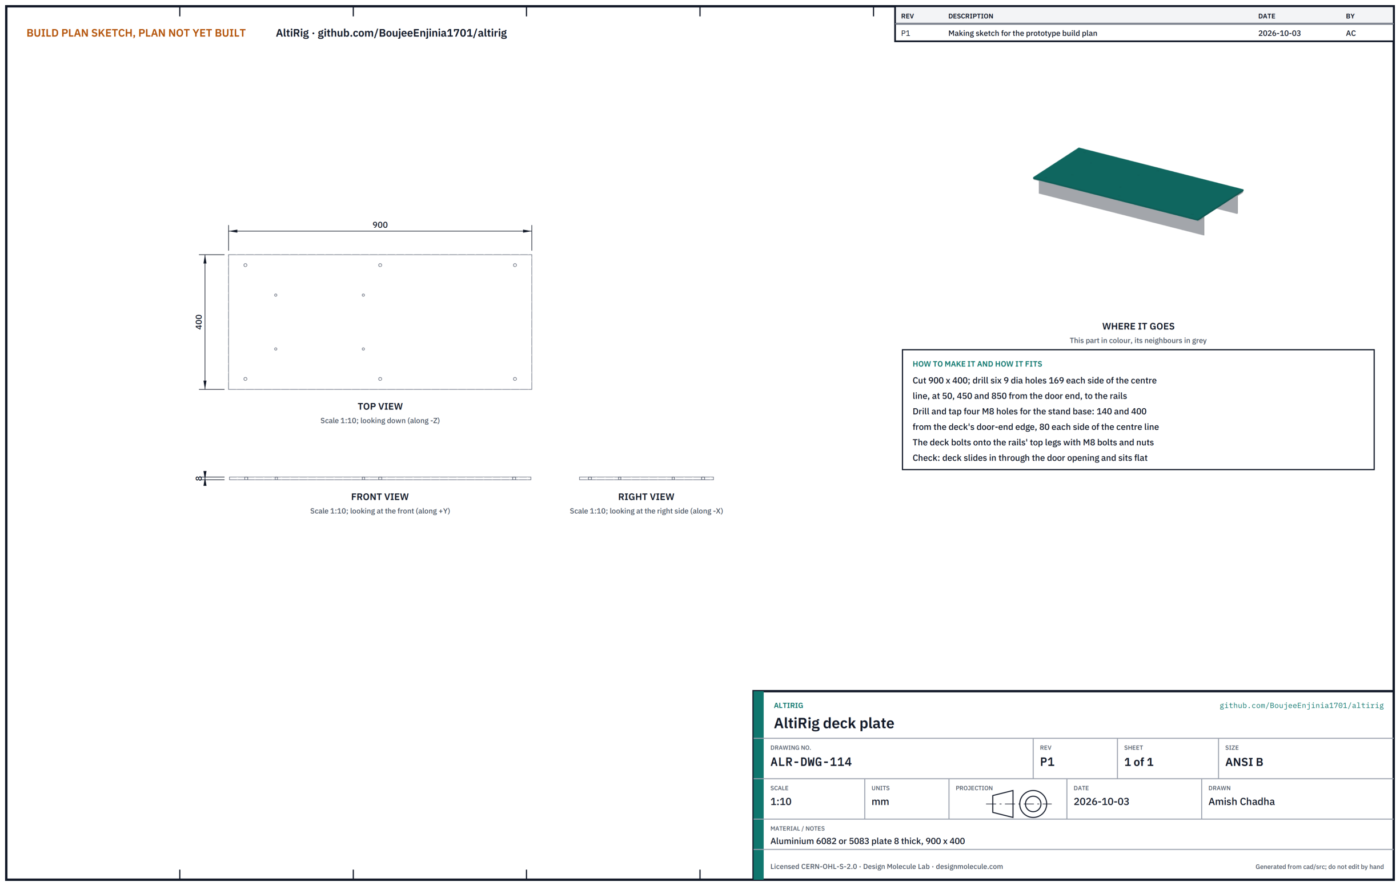
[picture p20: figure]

Figure 15. Deck plate (ALR-DWG-114).
What it is and what it is made from. Aluminium plate 8 mm thick, 900 x 400 mm.
How to make it. Drill six 9 mm holes 169 mm each side of the centre line at 50, 450 and 850 mm from the door-end edge, to match the rails. Drill and tap four M8 holes for the stand base at 140 and 400 mm from the door-end edge, 80 mm each side of the centre line.
How it fits the parts next to it. It slides in through the door onto the rails' top legs and is bolted down with six M8 bolts and nuts (Figure 32).
Check before moving on. The deck sits flat on both rails.

### 3.15 Baffle plate

Figure 16. Baffle plate (ALR-DWG-115).
What it is and what it is made from. A 790 mm disc of 2 mm perforated steel with 22 mm square holes on a 24.5 mm square pitch, so 80 % of it is open and the bars between the holes are 2.5 mm wide (Amish's decision 41B). It weighs about 1.5 kg.
How to make it. Cut the disc and file the rim smooth, removing any sharp part-holes or loose slivers at the edge. Drill four 9 mm holes at 45°, 135°, 225° and 315° on a 764 mm circle to match the tabs.
How it fits the parts next to it. It bolts to the four tabs with M8 bolts, 590 mm downstream of the propeller, with a 5 mm gap to the wall (Figure 35). It is taken out for the comparison runs without it.

Figure 35. Joint 7: the baffle bolted to a tab welded inside the shell. Check before moving on. The gap to the wall is even all round.

### 3.16 Stand base plate

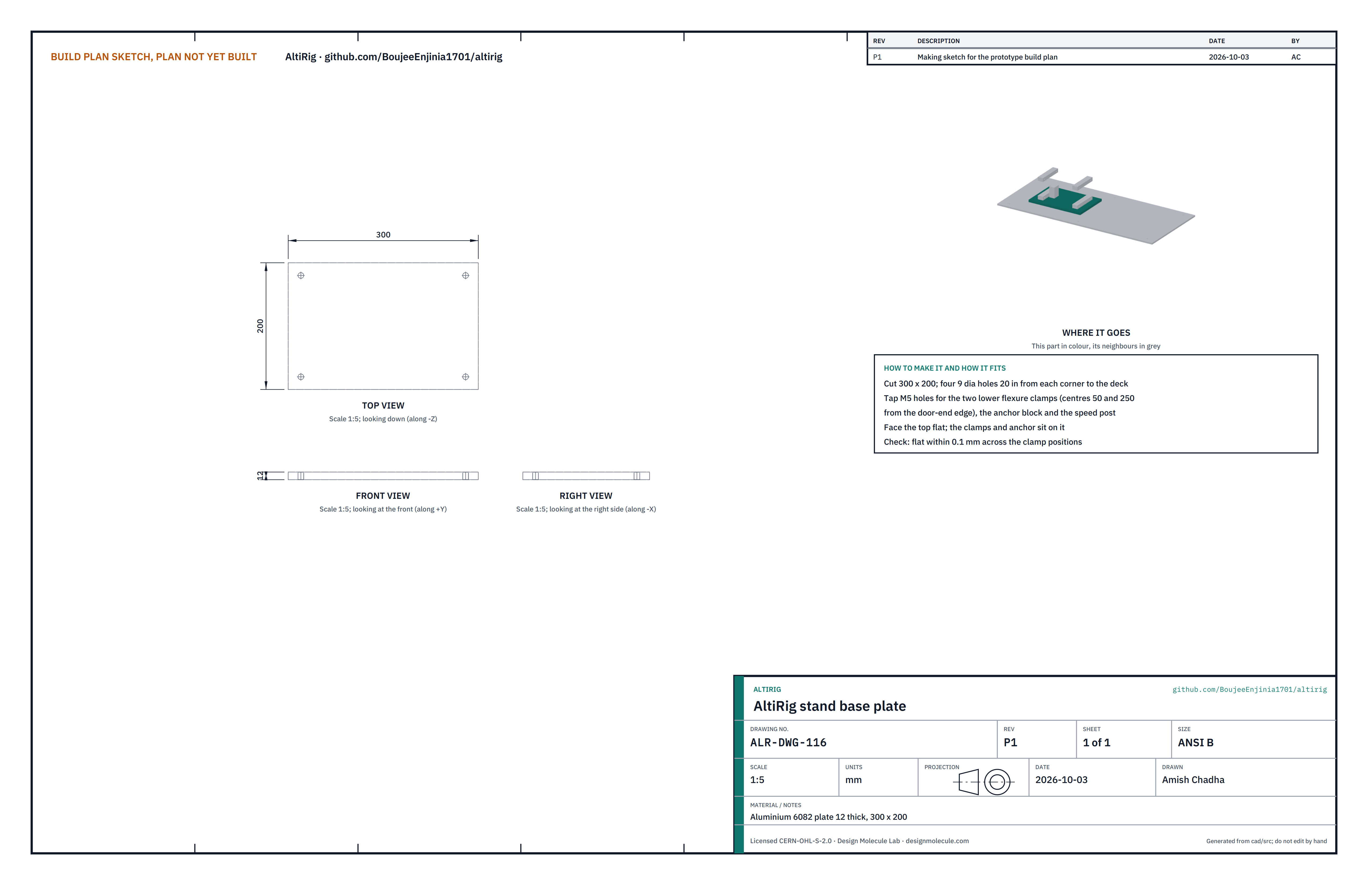
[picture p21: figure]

Figure 17. Stand base plate (ALR-DWG-116).
What it is and what it is made from. Aluminium plate 12 mm thick, 300 x 200 mm.
How to make it. Drill four 9 mm holes 20 mm in from each corner, counterbored for the M8 screws into the deck. Tap M5 holes for the two lower flexure clamps (centres 50 mm and 250 mm from the door-end edge), the anchor block and the speed sensor post. Face the top flat.
How it fits the parts next to it. It is screwed to the deck; the lower clamps, the anchor block and the speed post screw onto it (Figure 33).
Check before moving on. Flat to 0.1 mm across the clamp positions.

### 3.17 Flexure leaves and clamps

Figure 18. Flexure leaves and clamps (ALR-DWG-117).
What it is and what it is made from. Two leaves 120 x 110 mm cut from 0.5 mm hardened spring steel shim, and four aluminium clamp blocks 30 x 140 x 20 mm.
How to make it.
Cut the leaves with snips or a guillotine. Do not bend or kink them.
Slit each clamp block along its middle so a leaf is gripped between the two halves; drill for two M5 screws.

How it fits the parts next to it. The two lower clamps screw to the base plate 200 mm apart; the two upper clamps screw to the underside of the carriage. Each leaf is gripped 15 mm deep at top and bottom, with 80 mm free between the clamps, so the leaves stand parallel and the carriage can move a fraction of a millimetre along the axis (Figure 33). Set the height with an 80 mm spacer block between the clamps while tightening.

1.
2.

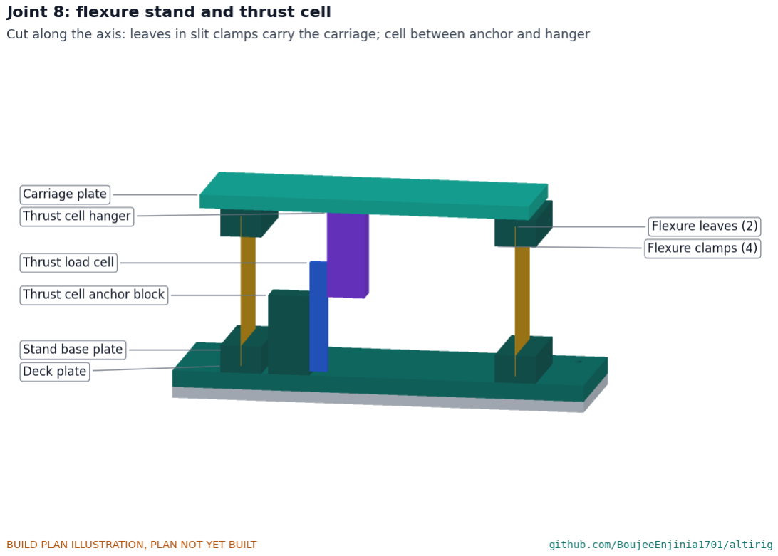
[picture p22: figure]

Figure 33. Joint 8: the leaves in their clamps between the base plate and the carriage, and the thrust cell between the anchor and the hanger, cut along the axis.
Check before moving on. The carriage moves freely along the axis and springs back to the same place.

### 3.18 Thrust cell anchor block and hanger

Figure 19. Anchor block and hanger (ALR-DWG-118).
What it is and what it is made from. Two blocks of aluminium bar: the anchor 30 x 40 x 58 mm and the hanger 27 x 40 x 62 mm.
How to make it. Drill and tap each for two M5 screws to its plate (the anchor down into the base plate, the hanger up into the carriage) and two M5 screws to the load cell.
How it fits the parts next to it. The 10 kg bar load cell stands upright between them: its lower end is screwed to the anchor's face and its upper end to the hanger's face. The propeller's thrust pushes the carriage, which pushes the top of the cell (Figure 33).
Check before moving on. The cell hangs plumb and touches nothing between its two ends.

### 3.19 Carriage plate

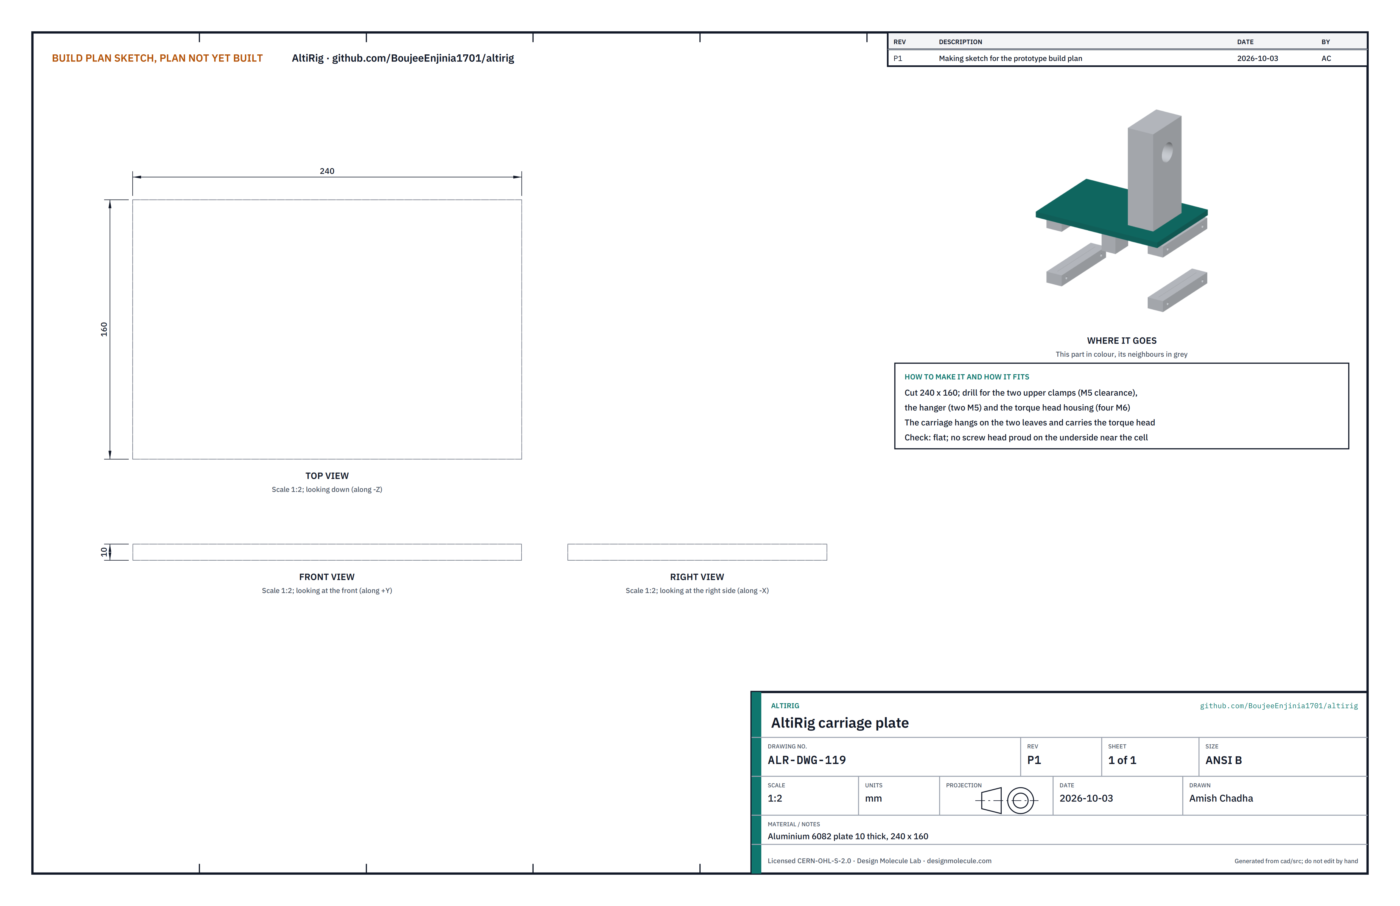
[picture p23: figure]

Figure 20. Carriage plate (ALR-DWG-119).
What it is and what it is made from. Aluminium plate 10 mm thick, 240 x 160 mm.
How to make it. Drill for the two upper clamps (M5 clearance), the hanger (two M5) and the torque head housing (four M6).
How it fits the parts next to it. It hangs on the two leaves through the upper clamps and carries the torque head. Check before moving on. Flat; no screw head proud on its underside near the cell.
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

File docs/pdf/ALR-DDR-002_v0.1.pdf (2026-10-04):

A LT I R I G · D E S I G N D E C I S I O N R E C O R D

# AltiRig design for construction

### Design Molecule Lab · designmolecule.com

D O C U M E N T CO N T RO L

Document ID | ALR-DDR-002 | Version | 0.1
Status | Draft | Date | 2026-10-03
Author | Amish Chadha | License | CERN-OHL-S-2.0
Project TRL | TRL 3 | Proof of concept
Repository | github.com/BoujeeEnjinia1701/altirig
Source | docs/decisions/0002-design-for-construction.md @ uncommitted

R EV I S I O N H I STO RY

Version | Date | Author | Change
0.1 | 2026-10-03 | Amish Chadha | Constructability review and changes C1 to C17, decided under Amish's 2026-10-03 pre-approvals

D R A F T · N O T F O R F A B R I C A T I O N

# 0002: Design for construction
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

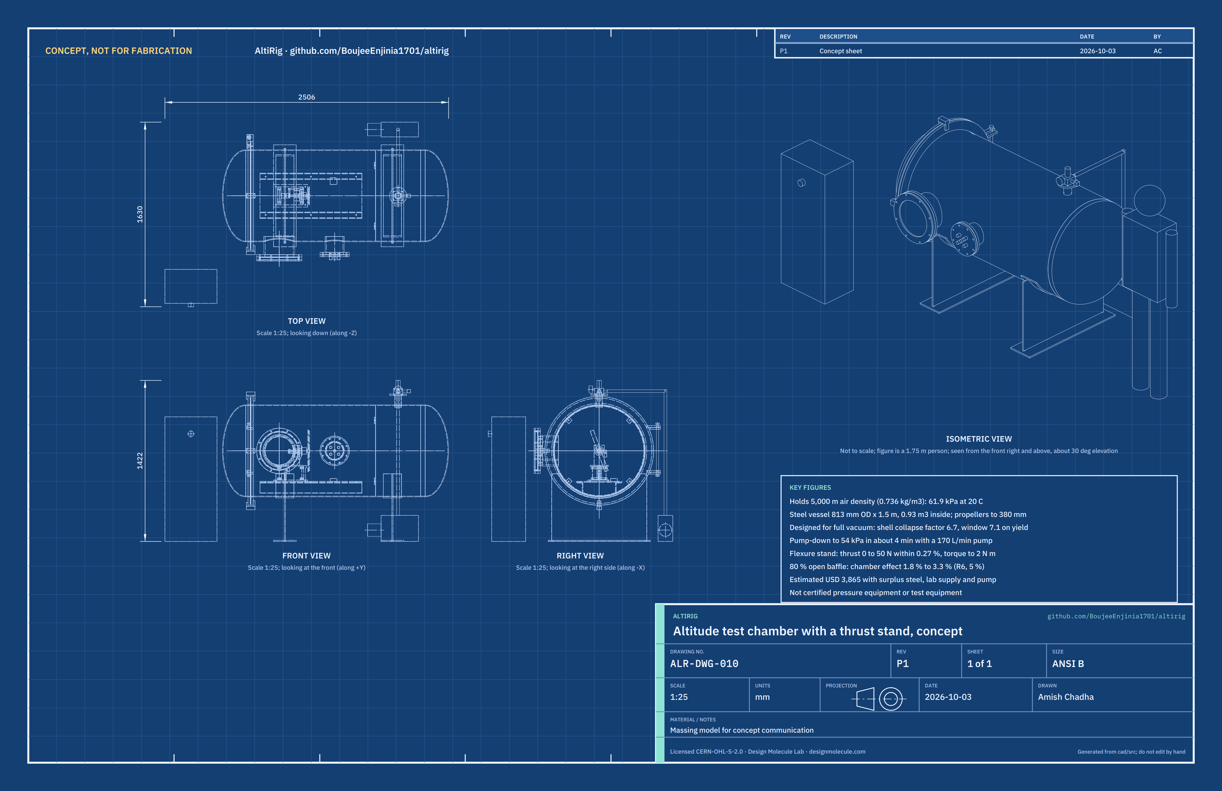
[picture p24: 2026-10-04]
media/concept-blueprint.png

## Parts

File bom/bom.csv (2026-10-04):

item | qty | spec | supplier | unit_cost_usd | make_buy | notes
1 Shell | 1 | Steel pipe offcut 813 mm OD x 6.35 mm wall (32 in x 0.25 in), welded line pipe or water pipe (API 5L, ASTM A53 or A139 class), 1,500 mm long, ends cut square within 1 mm; out-of-roundness no more than 1 % of diameter; holes for the window, feed-through and manifold nozzles cut on site; about 185 kg | Pipe yard or steel stockholder (surplus offcut or remnant) | 150.00 | make | Surplus offcut (decision 42B, 2026-10-03); price basis: about 185 kg of surplus pipe at about USD 0.80 a kg, typical of scrap-plus yard prices for line-pipe remnants (new-cut length about USD 420). Accept only after the roundness and thickness checks in the design decisions register (out-of-roundness no more than 8 mm, wall no less than 5.9 mm anywhere; ALR-CAL-001 section B)
2 Flange rings | 2 | S275 or A36 steel plate 20 mm, ring 960 mm OD x 813 mm ID, plasma or waterjet cut; one welded to the shell end, one to the door head; faces flat within 1 mm after welding | Plate cutting service | 140.00 | make | Indicative price each including about 32 kg of plate and cutting
3 Dished heads | 2 | 2:1 semi-ellipsoidal tank head, 813 mm OD, 6.35 mm, carbon steel, 40 mm straight flange; one welded to the rear of the shell, one to the door flange ring | Tank head supplier or surplus dealer (second-hand or overstock) | 130.00 | buy | Surplus or overstock head (decision 42B, 2026-10-03); price basis: about half the new price of USD 260 each (about USD 3.30 a kg for 39 kg), typical for unused overstock or heads cut from a scrapped receiver. Outside diameter, thickness (no less than 5.9 mm) and skirt length checked against the pipe before purchase
4 Window nozzle and flange | 1 | Pipe stub 273.1 mm OD x 12.7 mm wall (10 in XS), 160 mm long, ends cut square (set-in nozzle); 20 mm steel ring 400 mm OD x 255 mm ID with eight M10 tapped holes on a 373 mm circle | Pipe and plate stockholder | 110.00 | make | Indicative price for the stub and the cut ring
5 Feed-through nozzle and flange | 1 | Pipe stub 168.3 mm OD x 10.97 mm wall (6 in XS), 140 mm long, ends cut square (set-in nozzle); 20 mm steel ring 260 mm OD x 154 mm ID with eight M10 tapped holes on a 225 mm circle | Pipe and plate stockholder | 70.00 | make | Indicative price
6 Manifold stub and flange | 1 | Pipe stub 60.3 mm OD x 3.91 mm wall (2 in schedule 40), 105 mm long; 12 mm steel disc 150 mm with a 52.5 mm bore and four M8 tapped holes on a 110 mm circle | Pipe and plate stockholder | 30.00 | make | Indicative price
7 Saddles | 2 | Welded from 10 mm steel plate: wear plate 160 mm wide rolled to 813 mm inside diameter over 120 degrees, web 840 mm wide x 597 mm high with a curved top, base plate 200 x 900 mm with two 18 mm holes; about 55 kg each | Plate cutting service and welding shop | 120.00 | make | Indicative price each; welded to the shell
8 Deck rails | 2 | Steel equal angle 50 x 50 x 6 mm, 900 mm long, three 9 mm holes in the top leg; welded inside the shell | Steel stockholder | 15.00 | make | Indicative price each
9 Baffle tabs | 4 | Steel flat 40 x 10 mm, 45 mm long, one 9 mm hole; welded inside the shell 1,100 mm from the flange face | Steel stockholder | 2.50 | make | Indicative price each
10 Hinge | 1 | Four lugs from 15 mm steel plate with 21 mm holes, two welded to each flange ring; hinge pin 20 mm 4140 or 1045 bar, 450 mm long, with welded head and collar | Plate cutting service and machine shop | 45.00 | make | Indicative price for the set
11 Gaskets | 1 | Door: closed-cell EPDM sponge strip 6 x 45 mm, about 2.8 m, glued to the shell ring face with contact adhesive; window and feed-through: solid EPDM 6 mm and 2 mm sheet cut to rings | Gasket and rubber supplier | 60.00 | buy | Indicative price for all three gaskets and the adhesive
12 Latch clamps | 3 | Heavy-duty adjustable latch (toggle) clamp, holding force at least 3 kN, steel, bolt-on base | Industrial supplier | 30.00 | buy | Indicative price each; pull the door onto the gasket for the first pump-down
13 Polycarbonate window | 1 | Clear polycarbonate sheet 20 mm (not acrylic), cut to a 340 mm disc, edges sanded smooth and lightly chamfered; protective film left on until fitted | Plastics stockholder | 70.00 | make | Indicative price; acrylic is not allowed (it shatters)
14 Window spacer and clamp rings | 1 | Spacer: 25 mm steel ring 400 mm OD x 346 mm ID; clamp: 10 mm steel ring 400 mm OD x 290 mm ID; both with eight 11 mm holes on a 373 mm circle | Plate cutting service | 90.00 | make | Indicative price for both rings
15 Feed-through plate | 1 | Aluminium 6082 plate 15 mm cut to a 260 mm disc, eight 11 mm holes on a 225 mm circle and five 20 mm holes; five M20 nickel-brass IP68 cable glands; two-part epoxy potting for the cables | Aluminium stockholder and electrical supplier | 70.00 | make | Indicative price
16 Deck plate | 1 | Aluminium 6082 or 5083 plate 8 mm, 900 x 400 mm, six 9 mm holes to the rails, four M6 tapped holes for the stand | Aluminium stockholder | 85.00 | make | Indicative price
17 Baffle plate | 1 | Perforated steel sheet 2 mm, 22 mm square holes on a 24.5 mm square pitch (80 % open, 2.5 mm bars), cut to a 790 mm disc with four 9 mm holes on the tab positions; about 1.5 kg | Perforated metal supplier | 85.00 | make | Decision 41B (2026-10-03); price basis: the USD 75 indicative price of the 63 % sheet plus about USD 10 for a less common square-hole pattern (perforated metal supplier stock sheet, cut to size). Bolted so it can be taken out for the R6 comparison runs
18 Stand base plate | 1 | Aluminium 6082 plate 12 mm, 300 x 200 mm, four 9 mm counterbored holes, tapped holes for the clamps, anchor block and speed post | Aluminium stockholder | 25.00 | make | Indicative price
19 Flexure leaves and clamps | 1 | Two leaves 120 x 110 mm cut from 0.5 mm hardened spring steel shim (1095 blue-tempered or 301 full-hard stainless); four aluminium clamp blocks 30 x 140 x 20 mm, each slit and clamped with two M5 screws | Shim stock supplier and aluminium stockholder | 35.00 | make | Indicative price for the set
20 Thrust cell anchor block and hanger | 1 | Aluminium 6082 bar: anchor block 30 x 40 x 58 mm and hanger 27 x 40 x 62 mm, each drilled and tapped M5 for the load cell | Aluminium stockholder | 15.00 | make | Indicative price for both
21 Carriage plate | 1 | Aluminium 6082 plate 10 mm, 240 x 160 mm, holes for the clamps, hanger and torque head | Aluminium stockholder | 15.00 | make | Indicative price
22 Torque head | 1 | Housing: aluminium 6082 block 50 x 90 x 178 mm bored 35 mm H7 through on the axis for two 6202-2RS bearings; shaft: 15 mm stainless 303 bar, 115 mm long with a 40 mm hub; motor plate: 6 mm aluminium disc 80 mm drilled for 16, 19, 25 and 30 mm motor patterns | Machine shop | 75.00 | make | Indicative price including boring and turning
23 Torque arm and cell bracket | 1 | Aluminium 6082: arm 10 mm thick, 30 mm hub clamped on the shaft, 60 mm reach to the cell; bracket 40 x 21 x 33 mm bolted to the housing side | Aluminium stockholder | 20.00 | make | Indicative price for both
24 Load cells and amplifiers | 1 | Bending-beam bar load cells 12.7 x 12.7 x 80 mm, C3 class or better: one 10 kg (thrust) and one 5 kg (torque); two 24-bit load-cell amplifier boards, 80 samples per second, in shielded leads | Electronics distributor | 60.00 | buy | Indicative price for the set
25 Speed sensor | 1 | Infrared reflective optical sensor, at least 20 kHz response, on an aluminium post 16 x 20 x 128 mm; reflective tape on the propeller | Electronics distributor | 25.00 | make | Indicative price including the post
26 Motor under test (example) | 1 | Brushless outrunner for 15 in propellers on 6S, about 58 mm diameter and 40 mm long, with a 16 or 19 mm mounting pattern | Drone parts supplier | 90.00 | buy | Example test article; users bring their own
27 Propeller under test (example) | 1 | Two-blade carbon propeller 15 x 5 in (381 x 127 mm) | Drone parts supplier | 35.00 | buy | Example test article; users bring their own
28 Valve manifold | 1 | Steel fittings on the 2 in stub flange: adjustable vacuum relief valve set to open at 55 kPa below atmosphere; 63 mm vacuum gauge 0 to -100 kPa; normally-open solenoid bleed valve 1/4 in with needle valve (vents the chamber on power loss); manual vent ball valve 1/2 in; isolation ball valve 1 in to the pump hose | Pneumatics and vacuum supplier | 220.00 | buy | Indicative price for the fittings and valves
29 Vacuum pump (host lab) and hose | 1 | Host lab or workshop single-stage rotary vane vacuum pump, 6 CFM (170 L/min) free air as calculated and no less than 5 CFM (140 L/min), with thermal overload and oil-mist exhaust filter (supplied by the host lab); bought: 2.5 m of 25 mm bore wire-reinforced vacuum hose with clamps and an adapter to the pump inlet | Host lab (pump); refrigeration or vacuum supplier (hose and adapter) | 45.00 | buy | Decision 42B (2026-10-03): the host lab's existing pump is used, so only the hose, clamps and adapter are bought; price basis: about USD 12 a metre for wire-reinforced vacuum hose plus about USD 15 for clamps and a barbed adapter. A new pump would be about USD 260. A pump below 140 L/min would not meet R8's 5 min pump-down (ALR-CAL-001 C and H). Exhaust led outdoors or to an extract
30 Control cabinet | 1 | Floor-standing steel enclosure about 460 x 300 x 1,100 mm on a plinth, with a mains inlet protected by a 30 mA residual current device, earth bar, DIN rail, terminals and cooling fan | Electrical wholesaler | 180.00 | buy | Indicative price
31 Air sensors | 1 | Two barometric pressure sensors with absolute accuracy of 50 Pa or better (BMP390 class), one humidity sensor, two class A PT1000 temperature probes with amplifiers, in a vented printed housing on the deck | Electronics distributor | 60.00 | buy | Indicative price for the set
32 Motor power supply (host lab) | 1 | Host lab's existing programmable DC power supply, 24 V adjustable 20 to 28 V, at least 1,500 W (62 A), overcurrent protection; switched through the interlocked motor contactor (line 35), using its remote on/off input where it has one | Host lab (existing equipment) | 0.00 | buy | Decision 42B (2026-10-03): uses the host lab's DC supply at no cost to the project; a new supply would be about USD 320. The supply stays outside the chamber and is fed through the interlocked contactor and emergency stop in the cabinet (R11); a smaller supply limits the thrust at 5,000 m density (ALR-CAL-001 E)
33 ESC and power sensor | 1 | Electronic speed controller 80 A for 6S, with throttle input from the controller; current and voltage sensor rated 100 A | Drone parts supplier | 100.00 | buy | Indicative price
34 Controller and logger | 1 | Microcontroller board with SD card and USB to a laptop, relay outputs for the pump, bleed valve and motor contactor; logs at 20 Hz to CSV | Electronics distributor | 50.00 | buy | Indicative price; firmware is TRL 4 work
35 Safety controls | 1 | Emergency stop button (red mushroom, latching), motor supply contactor, pump contactor, door interlock switch on a latch, key switch for motor arming | Electrical wholesaler | 180.00 | buy | Indicative price for the set
36 Fasteners and consumables | 1 | M8 to M10 bolts, nuts and washers for the deck, window and feed-through; M5 and M4 screws for the stand; contact adhesive, vacuum grease, thread sealant, epoxy, primer and paint | Hardware supplier | 90.00 | buy | Indicative price
37 Welding and fabrication labour | 1 | Welding shop: nozzles, flange rings, heads, saddles, rails, tabs and hinge lugs to the shell; full-penetration butt weld of the rear head; leak check of welds with soapy water under vacuum | Local welding and fabrication shop | 650.00 | buy | Indicative price; about 10 to 12 shop hours
38 Calibration kit | 1 | Calibration masses 0.5 kg to 5 kg, total 10 kg (OIML M2 class or better), a low-friction pulley on a bracket and a 100 mm calibration arm for the torque head | Laboratory supplier | 120.00 | buy | Indicative price

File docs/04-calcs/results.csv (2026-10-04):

section | quantity | value | unit | requirement | note
A | ISA 5,000 m: temperature | -17.5 | C
A | ISA 5,000 m: pressure | 54.02 | kPa
A | ISA 5,000 m: density | 0.7361 | kg/m3 | R1
A | ISA 6,000 m: density | 0.6597 | kg/m3
A | 5,000 m density as a share of sea level | 60.09 | %
A | Chamber pressure for 5,000 m density at 15 C | 60.89 | kPa | R1
A | Chamber pressure for 5,000 m density at 20 C | 61.94 | kPa | R1
A | Chamber pressure for 5,000 m density at 25 C | 63 | kPa | R1
A | Chamber pressure for 5,000 m density at 30 C | 64.06 | kPa | R1
A | Density at 54.0 kPa and 20 C (pressure match, not density match) | 0.642 | kg/m3 |  | equals about 6,100 m: matching pressure at room temperature overshoots the density
A | Chamber pressure for 6,000 m density at 30 C (lowest working pressure needed) | 57.41 | kPa
A | Pressure difference at the R1 point (5,000 m density, 20 C) | 39.38 | kPa
A | Relief valve setting: lowest chamber pressure 46.3 kPa, difference | 55.02 | kPa | R12
A | Design pressure difference for the vessel (full vacuum) | 101.3 | kPa | R7 | conservative: the pump can reach near full vacuum if the relief valve sticks
B | Shell: unsupported length used (skirts plus a third of each head) | 1718 | mm
B | Shell: elastic buckling pressure (Windenburg and Trilling) | 1351 | kPa
B | Shell: long-cylinder lower bound (no end support) | 209.4 | kPa
B | Shell: plastic collapse pressure 2 x yield x t/D | 3671 | kPa
B | Shell: predicted collapse with 0.5 knock-down | 675.6 | kPa
B | Shell: collapse factor at full vacuum | 6.667 |  | R7 | target at least 4
B | Shell: factor at full vacuum even with no end support at all (long-cylinder bound x 0.5) | 1.034
B | Heads: equivalent sphere radius 0.9 D | 731.7 | mm
B | Heads: collapse factor at full vacuum | 40.26 |  | R7
B | Openings: shell thickness needed for factor 4 | 5.176 | mm
B | Window opening: area to replace | 641.1 | mm2
B | Window opening: area available (shell excess, nozzle wall outside and set-in) / needed | 1.711 |  | R7 | at least 1; no pad needed
B | Feed-through opening: area to replace | 378.8 | mm2
B | Feed-through opening: area available (shell excess, nozzle wall outside and set-in) / needed | 2.292 |  | R7 | at least 1; no pad needed
B | Window: span radius (gasket outer edge, simply supported) | 165 | mm
B | Window: bending stress at full vacuum | 8.715 | MPa
B | Window: factor on yield at full vacuum | 7.114 |  | R7 | rule used: at least 6 for plastic windows
B | Window: centre deflection at full vacuum | 2.589 | mm
B | Feed-through plate: bending stress at full vacuum (holes ignored) | 3.874 | MPa |  | 6082-T6 yield 250 MPa
B | Door: area inside the gasket line | 0.6151 | m2
B | Door: force holding it shut at the R1 point | 24.23 | kN | R11 | about 2.5 t: it cannot be opened under vacuum
B | Door: force at full vacuum | 62.33 | kN
B | Door: force at only 2 kPa below atmosphere | 1.23 | kN | R11
B | Door gasket: bearing stress at full vacuum | 0.4982 | MPa |  | sponge closes fully; rings take the load
B | Latches: force to compress the sponge 25 % for the first seal | 6.256 | kN
B | Latches: force each (3 latches) | 2.085 | kN |  | latches rated at least 3 kN
B | Hinge: door mass carried | 72 | kg
B | Hinge: horizontal force at each lug pair | 920.9 | N |  | 20 mm pin and 15 mm lugs: stresses under 10 MPa
C | Chamber free volume | 0.9281 | m3
C | Pump speed used (85 % of 170 L/min) | 144.5 | L/min
C | Pump-down time to 54.0 kPa | 4.04 | min | R8
C | Pump-down time to the R1 density at 20 C (61.9 kPa) | 3.161 | min
C | Leak allowance (free air) | 0.2 | L/min |  | equivalent pressure rise about 0.3 kPa/min at 54 kPa
C | Vent time through the 6 mm bleed orifice from 54 kPa to ambient | 128.6 | s | R11
D | Inside wall area | 5.264 | m2
D | Air mass at 5,000 m density | 0.6832 | kg
D | Air temperature rise above the wall at 1,500 W | 9.498 | K
D | Air thermal time constant | 4.348 | s
D | Wall warming rate at 1,500 W | 0.4163 | K/min
D | Pressure rise the controller must make to hold density as the air warms | 3.24 | %
D | Density error: pressure sensor (50 Pa) | 0.08072 | %
D | Density error: temperature probe (0.15 K) | 0.05117 | %
D | Density error: air temperature spread (1.5 K) | 0.5117 | %
D | Density error: humidity correction | 0.07 | %
D | Density error: control band | 0.3 | %
D | Density error: root sum square | 0.6049 | % | R2 | target within 1 %
E | 50 N with the example propeller, sea level, 20 C: speed | 8467 | rpm
E | 50 N with the example propeller, sea level, 20 C: shaft power | 1126 | W
E | 50 N with the example propeller, sea level, 20 C: torque | 1.27 | N m | R4
E | 50 N, sea level, 20 C: tip speed | 168.5 | m/s
E | 50 N with the example propeller, 5,000 m density: speed | 1.083e+04 | rpm
E | 50 N with the example propeller, 5,000 m density: shaft power | 1440 | W
E | 50 N with the example propeller, 5,000 m density: torque | 1.27 | N m | R4
E | 50 N, 5,000 m density: tip speed | 215.5 | m/s
E | Electrical power for 50 N at 5,000 m density (motor and ESC 80 %) | 1800 | W
E | Thrust the 1,500 W supply allows with the example propeller at 5,000 m density | 44.27 | N |  | stand range is 50 N; a larger supply is needed only for the heaviest propellers
E | Blade Reynolds number at 0.75 R, 6,000 rpm, sea level | 1.787e+05
E | Blade Reynolds number at 0.75 R, 6,000 rpm, 5,000 m | 1.092e+05
E | Flexures: stiffness of the two leaves together | 11.72 | N/mm
E | Flexures: share of thrust carried by the leaves (calibrated out) | 2.9 | % | R3
E | Flexures: carriage movement at 50 N | 0.1237 | mm
E | Flexures: leaf bending stress at 50 N | 5.8 | MPa
E | Flexures: buckling load of the leaves / weight carried | 16.72
E | Flexures: pitching moment from thrust above the cell | 9.25 | N m |  | taken as tension and compression in the leaves
E | Thrust error budget (cell 0.05 % of 98 N, cable drag 0.1 N, zero drift, masses, flexure 0.1 %) | 0.1334 | N | R3
E | Thrust error as a share of 50 N | 0.2668 | % | R3 | target no more than 1 %
E | Torque cell load at 2 N m | 33.33 | N | R4 | 5 kg cell, 49 N
E | Bearing friction torque at 50 N thrust | 0.001125 | N m
E | Torque error budget | 0.005695 | N m | R4
E | Torque error as a share of 2 N m | 0.2847 | % | R4 | target within 2 %
E | Speed: blade-pass rate at 11,000 rpm | 366.7 | Hz
E | Speed: timing error with a 1 microsecond timer, one revolution | 0.01833 | % | R4
E | Propeller tip to shell inside | 210.1 | mm | R5
E | Propeller tip to deck | 80 | mm | R5
E | Window edge from the propeller plane | 18.32 | deg | R11 | outside the 15 deg fragment zone
E | Feed-through edge from the propeller plane | 20.92 | deg | R11
E | Energy of a half blade (25 g) released at 50 N, 5,000 m density | 208.9 | J |  | 6.35 mm steel shell contains it
F | Disc area / chamber section | 0.2255
F | Vessel inside diameter / propeller diameter | 2.106
F | Baffle loss coefficient (80 % open, at the section velocity) | 0.5377
F | Extra loop loss, with the baffle | 0.2241 | dynamic heads
F | Chamber thrust excess, with the baffle: same power model | 1.834 | % | R6
F | Chamber thrust excess, with the baffle: same speed model | 3.332 | % | R6 | target within 5 %
F | Extra loop loss, baffle removed | 0.1695 | dynamic heads
F | Chamber thrust excess, baffle removed: same power model | 1.393 | % | R6
F | Chamber thrust excess, baffle removed: same speed model | 2.531 | % | R6 | target within 5 %
F | Superseded 63 % open baffle, same power model | 2.895 | % | R6 | before decision 41B
F | Superseded 63 % open baffle, same speed model | 5.255 | % | R6 | before decision 41B
F | Reserve: 1,016 mm vessel with the baffle, same power model | 0.6567 | % | R6
F | Reserve: 1,016 mm vessel with the baffle, same speed model | 1.194 | % | R6
F | Return flow speed along the wall at 50 N | 3.938 | m/s
G | Logging rate | 20 | Hz | R9 | load-cell amplifiers sample at 80 Hz
H | Estimated cost of the constructable design | 3865 | USD | R10 | surplus pipe and heads; host lab's DC supply and pump (decision 42B)
H | Value-engineering target | 1000 | USD
H | Over the value-engineering target by | 2865 | USD
H | R10 restated cost limit | 4000 | USD | R10
H | Under the restated R10 limit by | 135 | USD | R10
H | Saving from decision 42B against the TRL 3 parts | 1065 | USD |  | pipe, two heads, pump (hose kept), DC supply

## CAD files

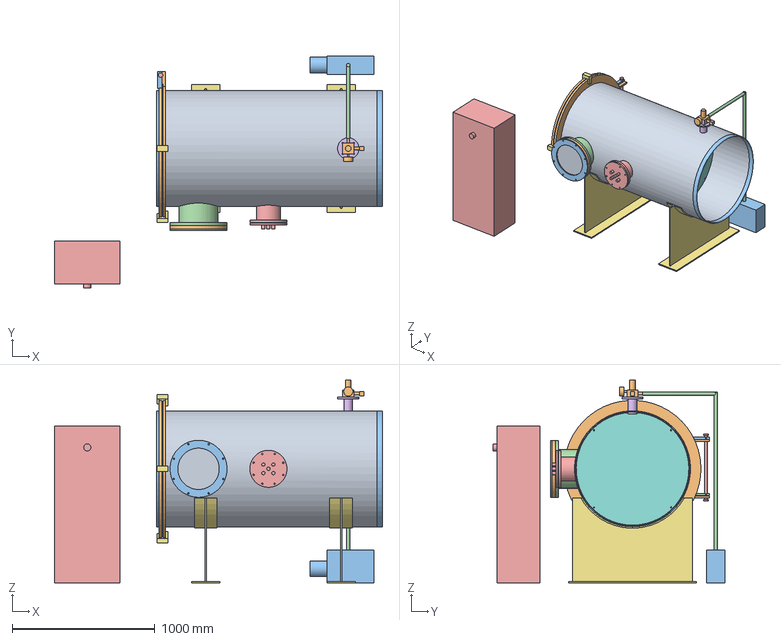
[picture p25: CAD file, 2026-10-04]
cad/step/altirig-assembly.step
2300.0 x 1630.0 x 1422.0 mm

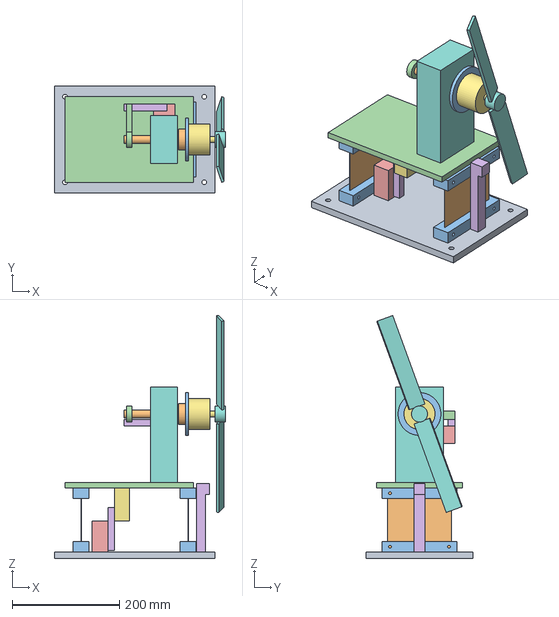
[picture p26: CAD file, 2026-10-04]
cad/step/altirig-stand.step
320.0 x 200.0 x 454.0 mm

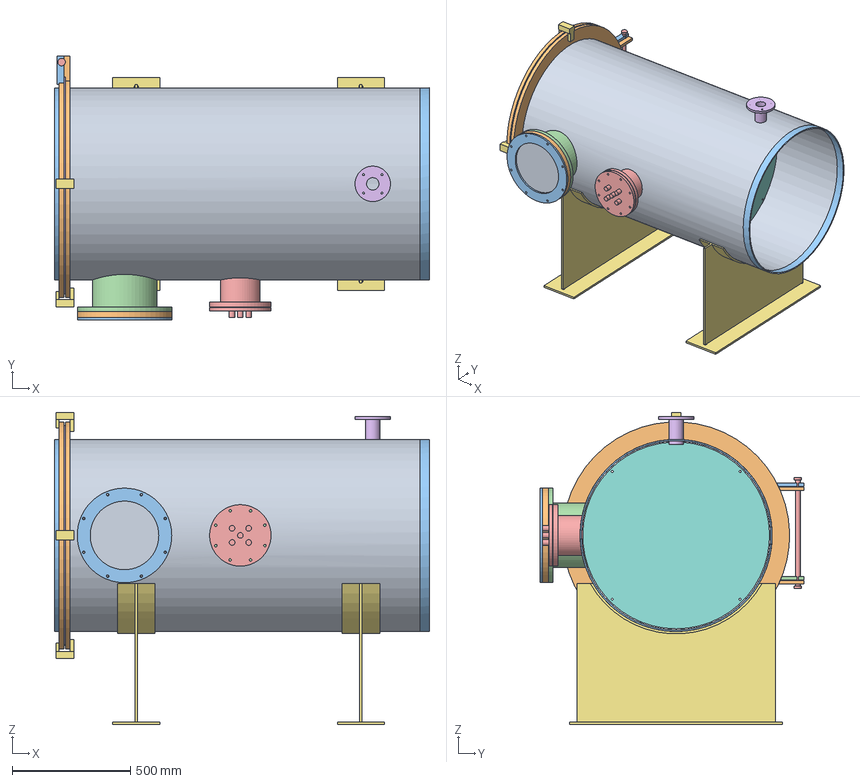
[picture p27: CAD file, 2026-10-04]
cad/step/altirig-vessel.step
1586.0 x 1115.0 x 1320.0 mm

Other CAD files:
cad/stl/altirig-assembly.stl
cad/stl/altirig-stand.stl

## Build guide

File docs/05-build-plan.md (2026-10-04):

---
doc_id: ALR-BLD-001
title: AltiRig prototype build plan
project: AltiRig
doc_type: Build plan
version: "0.2"
status: Draft
date: '2026-10-03'
author: Amish Chadha
license: CERN-OHL-S-2.0
revisions:
- version: "0.1"
  date: '2026-10-03'
  author: Amish Chadha
  change: First build plan; design made constructable (ALR-DDR-002)
- version: "0.2"
  date: '2026-10-03'
  author: Amish Chadha
  change: "Amish's decisions 41B (80 % open baffle) and 42B (surplus pipe and heads, host lab's DC supply and pump), ALR-DDR-003"
---

# AltiRig prototype build plan

**Plan, not yet built.** How to build the first proof-of-concept AltiRig, component by component. Building and testing to it is TRL 4 work. Decisions still to be made are kept in the design decisions register (`docs/06-design-decisions.md`), not here.

> **Safety:** AltiRig is a vacuum vessel with a spinning propeller inside, run from mains power. At the 5,000 m point the air presses on the vessel with 39 kPa and holds the door shut with about 24 kN (2.5 t). A collapsed vessel or a failed window can throw fragments, and a propeller can break at speed. Welding on the vessel is done by a qualified welder. Nothing is pumped down until a qualified engineer has reviewed the vessel calculation (ALR-CAL-001, section B), and the first pump-down is a proof test behind a guard (section 6). No battery goes inside the chamber. This is a prototype for testing, not certified pressure or test equipment.

## 1. What you are building

Figure 1. Every component, pulled apart and numbered in build order

*Figure 1. Every component pulled apart and numbered in build order: the vessel 1 to 18, window and feed-through 19 to 24, valve manifold, baffle and deck 25 to 27, the thrust stand 28 to 43, the motor and propeller under test 44 and 45, and the pump, hose and control cabinet 46 to 48.*

The prototype is a horizontal steel vacuum vessel about 2 m long and 813 mm in diameter, standing on two saddles with its axis 800 mm above the floor, with a flexure thrust stand inside. The vessel is a length of steel pipe with a bought dished head welded on the rear end; the door is a second head welded into a flange ring, hung on a hinge and pulled onto a sponge gasket by three latches. A polycarbonate window and a cable feed-through plate sit on short pipe nozzles on the near side, and a valve manifold sits on top. Inside, a deck carries the stand: a base plate, two spring-steel leaves holding a carriage, a load cell for thrust, a torque head on bearings with a second load cell, and a speed sensor. Twenty-two kinds of part are made, in a welding shop and a small machine shop: cutting pipe and plate, drilling and tapping, rolling one strip, welding, boring and turning. The valves, gaskets, load cells, electronics and test article are bought. The pipe and the two heads are bought surplus, and the host lab lends its DC power supply and vacuum pump (Amish's decision 42B). The parts cost about USD 3,865 from the bill of materials.

## 2. What changed to make it buildable

The TRL 2 concept named the parts but not how they are made or held. Each change keeps what the chamber does; all are recorded in decision record ALR-DDR-002.

*Table 1. Changes from the concept.*

| Component | The concept had | The buildable design has | Why |
| --- | --- | --- | --- |
| Shell | "A steel drum or tank" | An 813 x 6.35 mm pipe offcut with holes cut to the nozzle sizes | Stocked, round enough for the buckling calculation |
| Door seal | A door with no detail | Two flat 20 mm rings, one on the shell and one on the door head, with a sponge gasket between (Figure 26) | No machining; the sponge takes up weld distortion; vacuum closes the joint |
| Nozzles | A window and feed-throughs in the wall | Heavy-wall stubs set in through the wall and cut square, welded inside and out (Figures 28 and 29) | No contour cutting; the heavy wall replaces the steel removed, so no pads |
| Window | "A polycarbonate or laminated window" | 20 mm polycarbonate clamped over a spacer ring that sets the gasket squeeze (Figure 28) | Never over-clamped; no holes in the window |
| Feed-through | "Sealed connectors" | An aluminium plate with five potted IP68 cable glands (Figure 29) | Stock parts; potting stops leaks along the strands |
| Saddles, deck, baffle | Not shown | Welded saddles; two angles inside with a bolted deck; a bolted perforated baffle on four tabs (Figures 31, 32 and 35) | Something to stand on, build on and take out |
| Hinge and latches | Not shown | Lugs and a pin on the far side; three bolt-on latches (Figure 30) | Carry the 72 kg door and pull it on for the first seal |
| Thrust stand | "Load cells" | Two spring-steel leaves carrying a carriage; an upright bar cell between an anchor and a hanger (Figure 33) | No friction; a bending-beam cell is loaded across its length |
| Torque | "Reaction torque" | A torque head on two bearings, with an arm resting on a second cell (Figure 34) | Reads torque without thrust passing through it |
| Bleed valve | Any bleed valve | A normally-open valve | The chamber vents when power is lost |

## 3. Making the components

Sizes are in millimetres. "Door end" is the end with the door; distances along the vessel are measured from the face of the shell's flange ring. The window side is the near side in the pictures.

### 3.1 Shell

Figure 2. Making sketch, shell

*Figure 2. Shell (ALR-DWG-101).*

**What it is and what it is made from.** The body of the vessel: steel pipe 813 mm outside diameter with a 6.35 mm wall (32 in x 1/4 in), welded line pipe or water pipe, 1,500 mm long. About 185 kg. It is bought as a surplus offcut or remnant from a pipe yard.

**How to make it.**

1. Before buying, check the surplus pipe. Measure the diameter at three places around each end and in the middle: the largest less the smallest must be no more than 8 mm. Measure the wall at eight points around each end with a caliper or an ultrasonic gauge: it must be 5.9 mm or more everywhere. Reject a dented or deeply pitted pipe. The vessel's strength depends on both checks.
2. Cut the pipe 1,500 mm long with both ends square to within 1 mm.
3. Mark a straight line along the top. Mark the window hole centre 250 mm from the door end and the feed-through hole centre 740 mm from the door end, both on the side, a quarter turn from the top line. Mark the manifold hole 1,300 mm from the door end on the top line.
4. Cut the holes to the nozzle outside sizes plus 1 to 2 mm: 275 mm for the window, 170 mm for the feed-through, 62 mm for the manifold. Cut square to the pipe's axis. Grind smooth and bevel the outside edge.

**How it fits the parts next to it.** The flange ring slides over the door end, the rear head butts against the far end, the nozzles pass through the holes, and the saddles' wear plates take it from below. All are welded (steps 1 to 5).

**Check before moving on.** Holes on the right side and the right line; each nozzle stub slides in.

### 3.2 Flange rings (make 2)

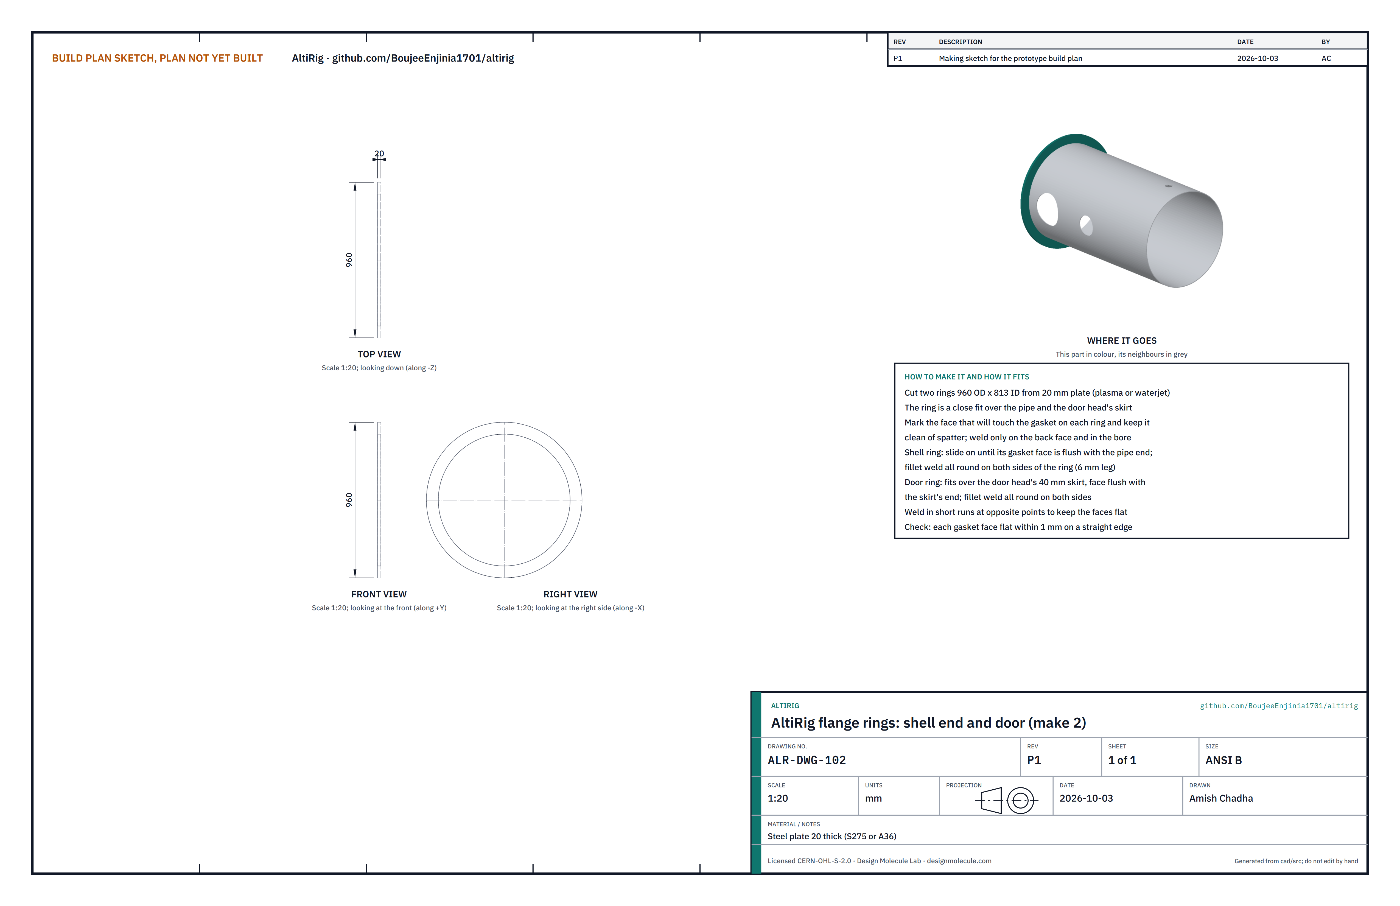
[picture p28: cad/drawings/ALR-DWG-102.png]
Figure 3. Making sketch, flange rings


*Figure 3. Flange rings (ALR-DWG-102).*

**What it is and what it is made from.** Two identical rings of 20 mm steel plate (S275 or A36), 960 mm outside, 813 mm inside. One goes on the shell's door end, one on the door head. The door seals between their faces.

**How to make it.**

1. Cut both rings by plasma or waterjet.
2. Mark the gasket face on each ring and keep it clean of spatter.
3. Check that each ring slides over the pipe end and over the door head's skirt with a close fit.

**How it fits the parts next to it.** The shell ring slides over the pipe until its gasket face is flush with the pipe end and is fillet welded on both sides (6 mm leg). The door ring goes over the door head's 40 mm skirt the same way. Weld in short runs at opposite points to keep the faces flat.

Figure 26. Joint 1, door closed on the shell ring

*Figure 26. Joint 1: the door ring against the gasket on the shell ring, with a latch over both rings.*

**Check before moving on.** After welding, each gasket face is flat to within 1 mm under a straight edge.

### 3.3 Window nozzle and flange

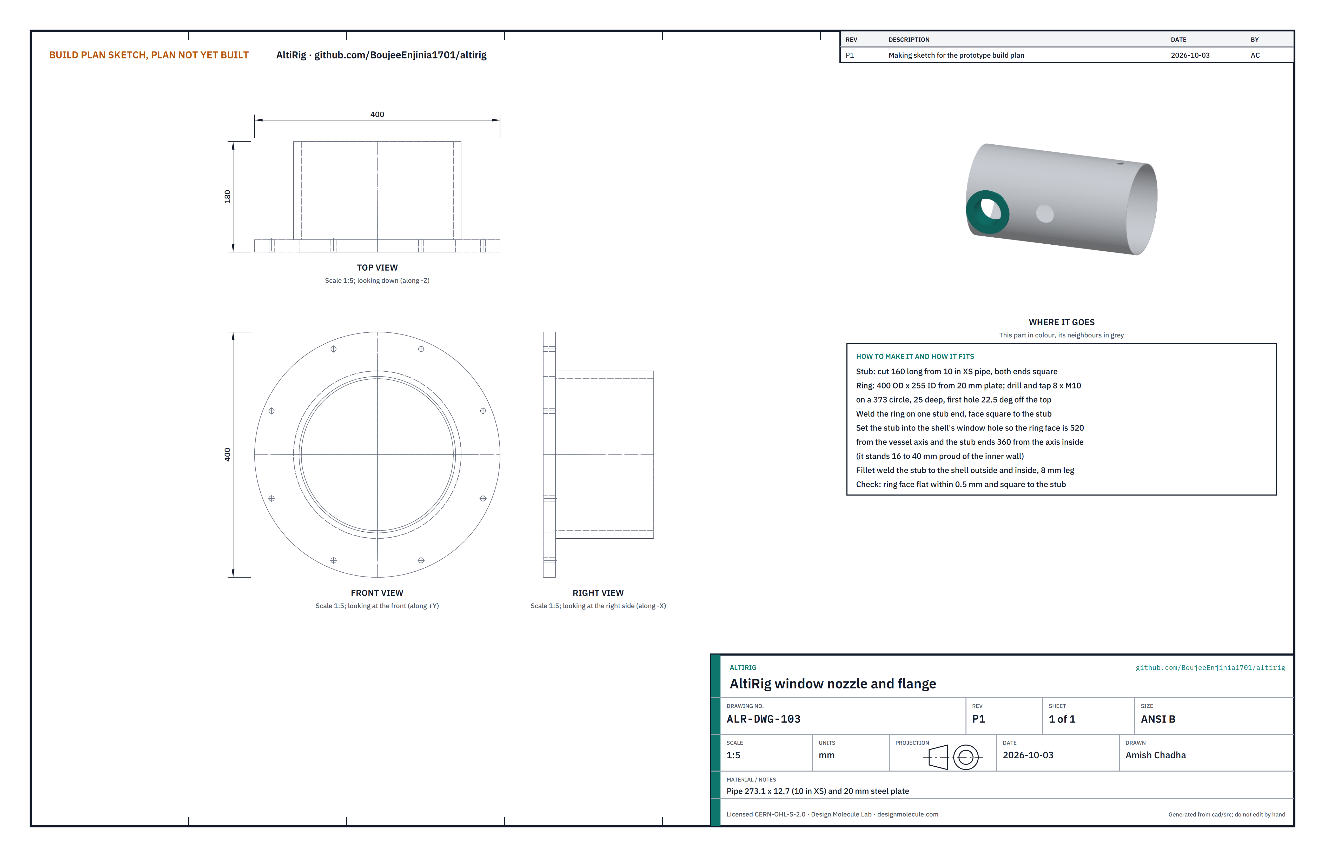
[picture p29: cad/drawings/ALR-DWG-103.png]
Figure 4. Making sketch, window nozzle


*Figure 4. Window nozzle and flange (ALR-DWG-103).*

**What it is and what it is made from.** A 160 mm stub of 273.1 mm pipe with a 12.7 mm wall (10 in XS) and a 20 mm steel ring, 400 mm outside and 255 mm inside.

**How to make it.**

1. Cut the stub 160 mm long, both ends square.
2. Cut the ring. Drill and tap eight M10 holes 25 mm deep on a 373 mm circle, the first 22.5° off the top.
3. Weld the ring onto one end of the stub, face square to the stub.

**How it fits the parts next to it.** The stub goes through the shell's window hole until the ring face is 520 mm from the vessel's axis; its inner end is then 360 mm from the axis and stands 16 to 40 mm proud of the inner wall. It is fillet welded to the shell outside and inside (8 mm leg). The window stack bolts to the ring (Figure 28).

**Check before moving on.** Ring face flat to 0.5 mm and square to the stub.

### 3.4 Feed-through nozzle and flange

Figure 5. Making sketch, feed-through nozzle

*Figure 5. Feed-through nozzle and flange (ALR-DWG-104).*

**What it is and what it is made from.** A 140 mm stub of 168.3 mm pipe with a 10.97 mm wall (6 in XS) and a 20 mm ring, 260 mm outside and 154 mm inside, with eight M10 tapped holes on a 225 mm circle.

**How to make it.** As the window nozzle: cut the stub square, cut and tap the ring, weld the ring on square.

**How it fits the parts next to it.** Set into the feed-through hole until the ring face is 500 mm from the axis; inner end 360 mm from the axis. Welded inside and out. The feed-through plate bolts to the ring (Figure 29).

**Check before moving on.** Ring face flat and square; the plate's holes line up with the tapped holes.

### 3.5 Manifold stub and flange

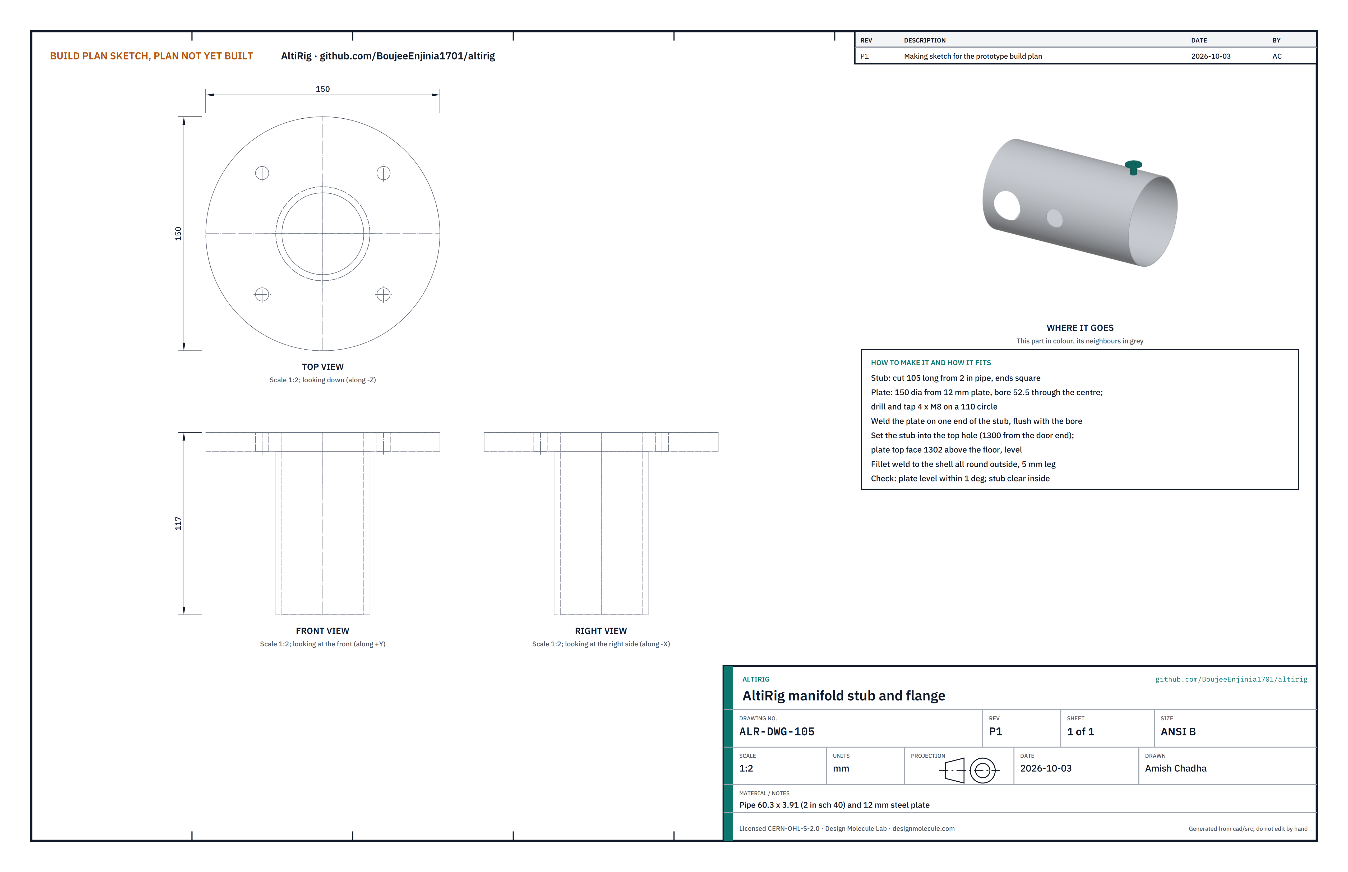
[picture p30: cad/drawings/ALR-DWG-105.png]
Figure 6. Making sketch, manifold stub


*Figure 6. Manifold stub and flange (ALR-DWG-105).*

**What it is and what it is made from.** A 105 mm stub of 60.3 mm pipe (2 in schedule 40) with a 150 mm disc of 12 mm plate on top, bored 52.5 mm and tapped for four M8 screws on a 110 mm circle.

**How to make it.** Cut the stub, cut and bore the disc, tap it, weld it to the stub flush with the bore.

**How it fits the parts next to it.** The stub goes into the top hole with the disc level, its top face 1,302 mm above the floor, and is fillet welded all round (5 mm leg). The valve manifold bolts on top (Figure 27).

**Check before moving on.** Disc level to within 1°.

### 3.6 Saddles (make 2)

Figure 7. Making sketch, saddle

*Figure 7. Saddle (ALR-DWG-106).*

**What it is and what it is made from.** A welded support of 10 mm plate: a 200 x 900 mm base plate, an 840 mm wide web 597 mm high with a curved top, and a 160 mm wear plate rolled to the shell's outside diameter over 120°. About 55 kg each.

**How to make it.**

1. Cut the base plate and drill two 18 mm holes 40 mm from each end.
2. Cut the web with an 833 mm curve in its top, the curve's centre 800 mm above the bottom of the base plate.
3. Roll the wear plate to 813 mm inside diameter.
4. Weld the web upright on the base's centre line, then the wear plate onto the web's curved top.

**How it fits the parts next to it.** The shell rests in the wear plates, which are welded to it along both edges (Figure 36). The base plates are bolted to the floor.

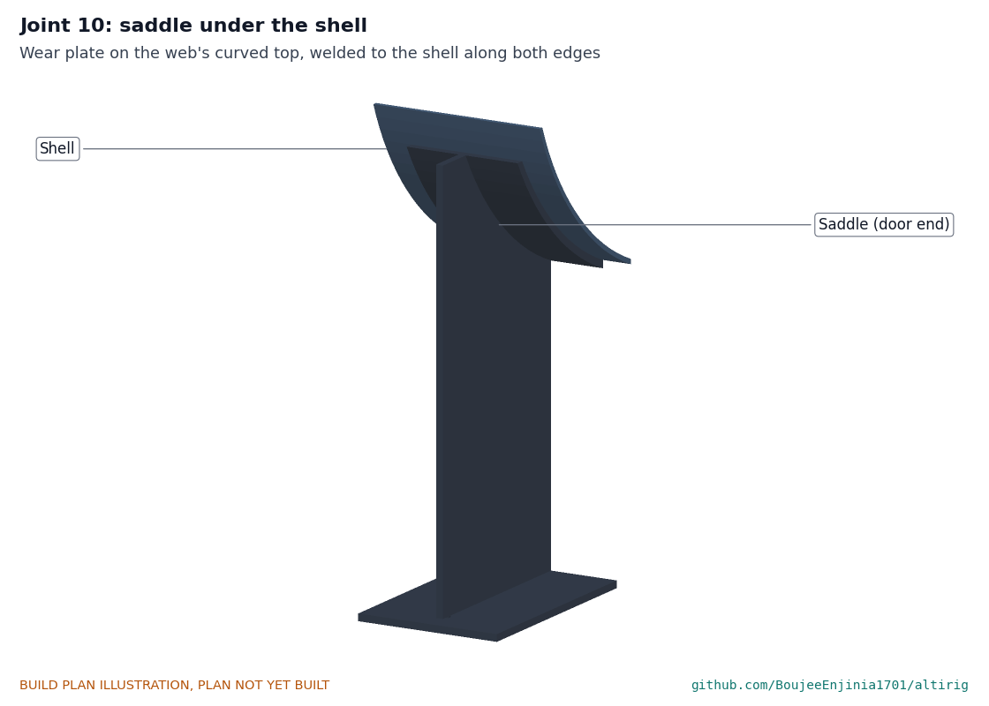
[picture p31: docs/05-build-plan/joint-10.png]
Figure 36. Joint 10, saddle under the shell


*Figure 36. Joint 10: the wear plate on the web's curved top, welded to the shell.*

**Check before moving on.** With both saddles on a level floor 950 mm apart, the shell's axis is level and 800 mm above the floor.

### 3.7 Deck rails (make 2)

Figure 8. Making sketch, deck rail

*Figure 8. Deck rail (ALR-DWG-107).*

**What it is and what it is made from.** Steel angle 50 x 50 x 6 mm, 900 mm long.

**How to make it.** Cut to length. Drill three 9 mm holes in one leg, 19 mm from its outer edge, at 50, 450 and 850 mm from the door end. Scribe the other leg to the inside of the shell and grind to a close fit.

**How it fits the parts next to it.** Inside the shell, the drilled leg is the top, flat and pointing out toward the wall, 522 mm above the floor; the hanging leg sits on the wall, 150 mm out from the centre line, so the rails are 300 mm apart. They start 80 mm from the shell ring face and are fillet welded along the hanging leg (Figure 32). The deck bolts on top.

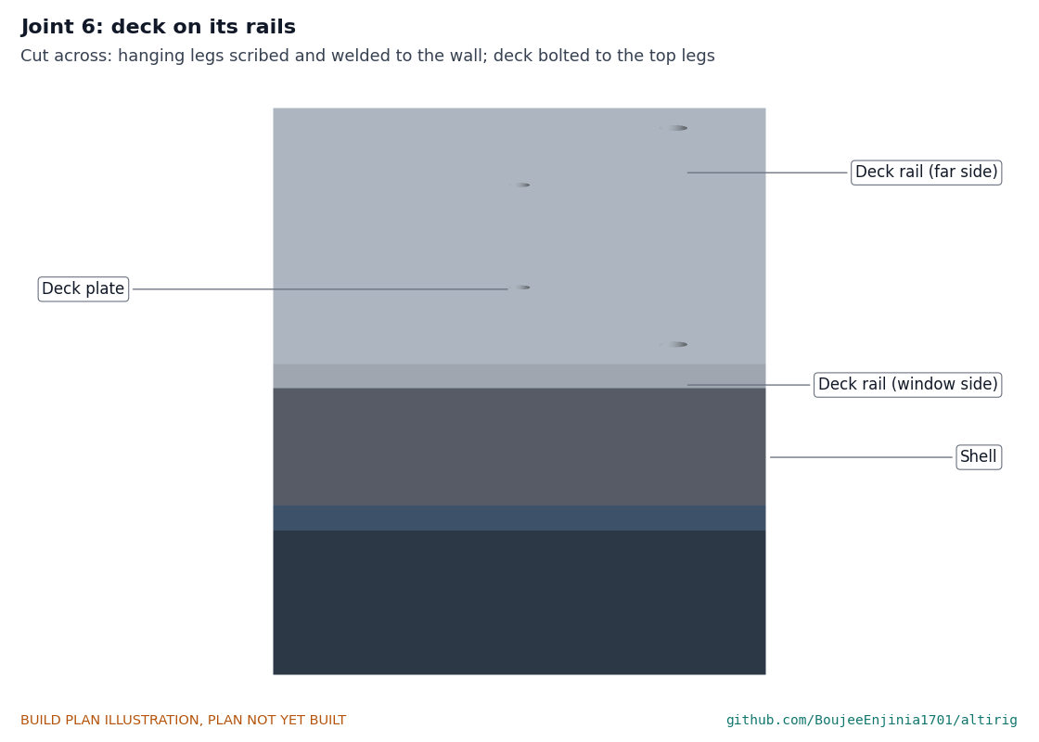
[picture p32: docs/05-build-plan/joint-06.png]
Figure 32. Joint 6, deck on its rails


*Figure 32. Joint 6: the rails welded inside the shell and the deck bolted to their top legs.*

**Check before moving on.** Both top legs level with each other to within 1 mm.

### 3.8 Baffle tabs (make 4)

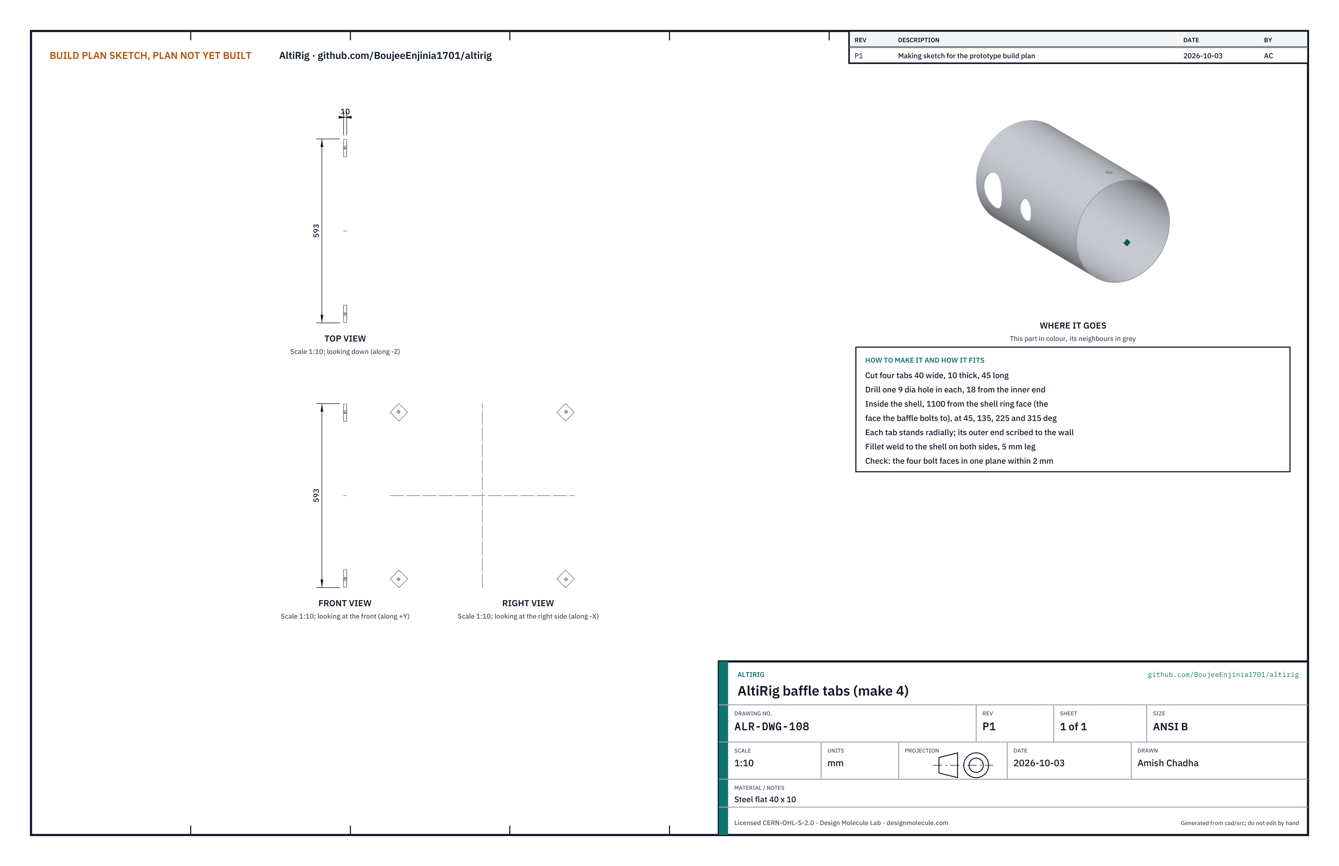
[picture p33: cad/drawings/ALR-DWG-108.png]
Figure 9. Making sketch, baffle tabs


*Figure 9. Baffle tabs (ALR-DWG-108).*

**What it is and what it is made from.** Four pieces of 40 x 10 mm steel flat, 45 mm long, each with one 9 mm hole 18 mm from its inner end.

**How to make it.** Cut, drill and scribe the outer end of each to the shell's curve.

**How it fits the parts next to it.** Welded inside the shell 1,100 mm from the shell ring face, standing toward the axis, at 45°, 135°, 225° and 315° from the top. The baffle bolts to their door-side faces (Figure 35).

**Check before moving on.** The four bolt faces lie in one plane to within 2 mm.

### 3.9 Hinge lugs and pin

Figure 10. Making sketch, hinge

*Figure 10. Hinge lugs and pin (ALR-DWG-109).*

**What it is and what it is made from.** Four lugs of 15 mm steel plate, each with a 21 mm hole, and a 20 mm steel pin 450 mm long with a head and a collar.

**How to make it.**

1. Cut the four lugs and drill the holes. Slot the two door lugs' holes 3 mm toward the vessel's axis.
2. Weld two lugs to the shell ring's far edge, 395 mm apart vertically, the upper one 190 mm above the axis.
3. Weld two lugs to the door ring's far edge, each 2 mm above a shell-ring lug.
4. Set all four holes on one vertical line with a rod before the welds cool.

**How it fits the parts next to it.** The pin drops through all four lugs from above; the hole centres are 16 mm in front of the shell ring face and 515 mm out from the axis (Figure 30).

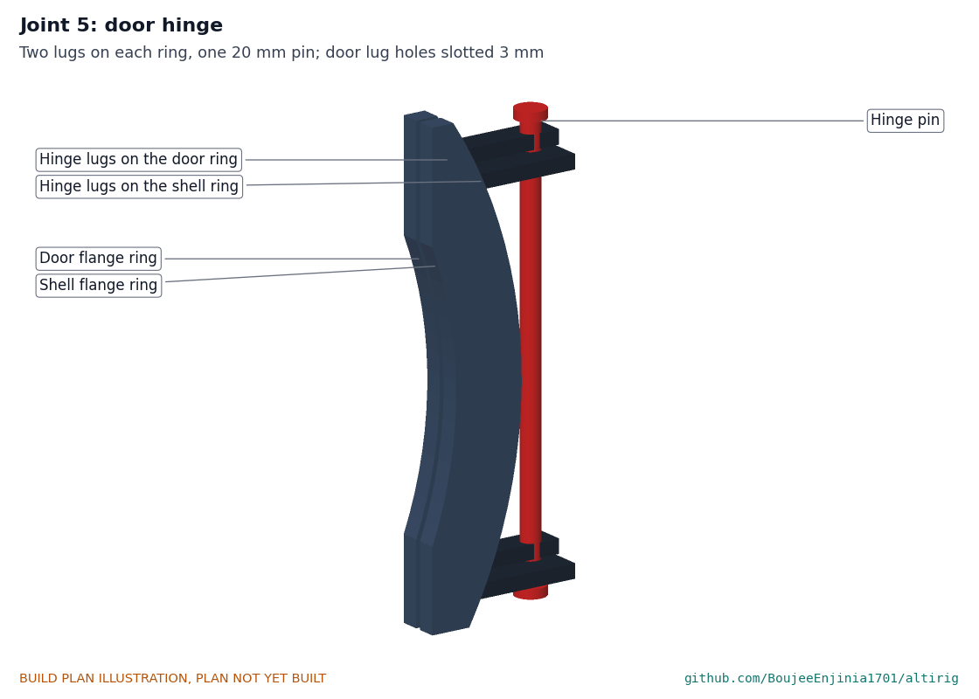
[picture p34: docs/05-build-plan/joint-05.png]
Figure 30. Joint 5, door hinge


*Figure 30. Joint 5: the lugs on both rings and the pin.*

**Check before moving on.** The door swings freely and closes square on the gasket.

### 3.10 Door

Figure 11. Making sketch, door

*Figure 11. Door: the second head welded into the second flange ring (ALR-DWG-110).*

**What it is and what it is made from.** A bought 2:1 ellipsoidal tank head, 813 mm outside diameter, 6.35 mm, with a 40 mm straight skirt, welded into the second flange ring, with the two door lugs. About 72 kg.

**How to make it.**

1. Set the ring over the head's skirt with its gasket face flush with the skirt's open end.
2. Fillet weld both sides in short balanced runs.
3. Grind the gasket face smooth where the welds meet it.

**How it fits the parts next to it.** The door hangs on the hinge and closes onto the gasket on the shell ring; three latches hold it for the first seal (Figure 26).

**Check before moving on.** Gasket face flat; no weld proud of it. Lift the door only with a hoist or two people.

### 3.11 Window

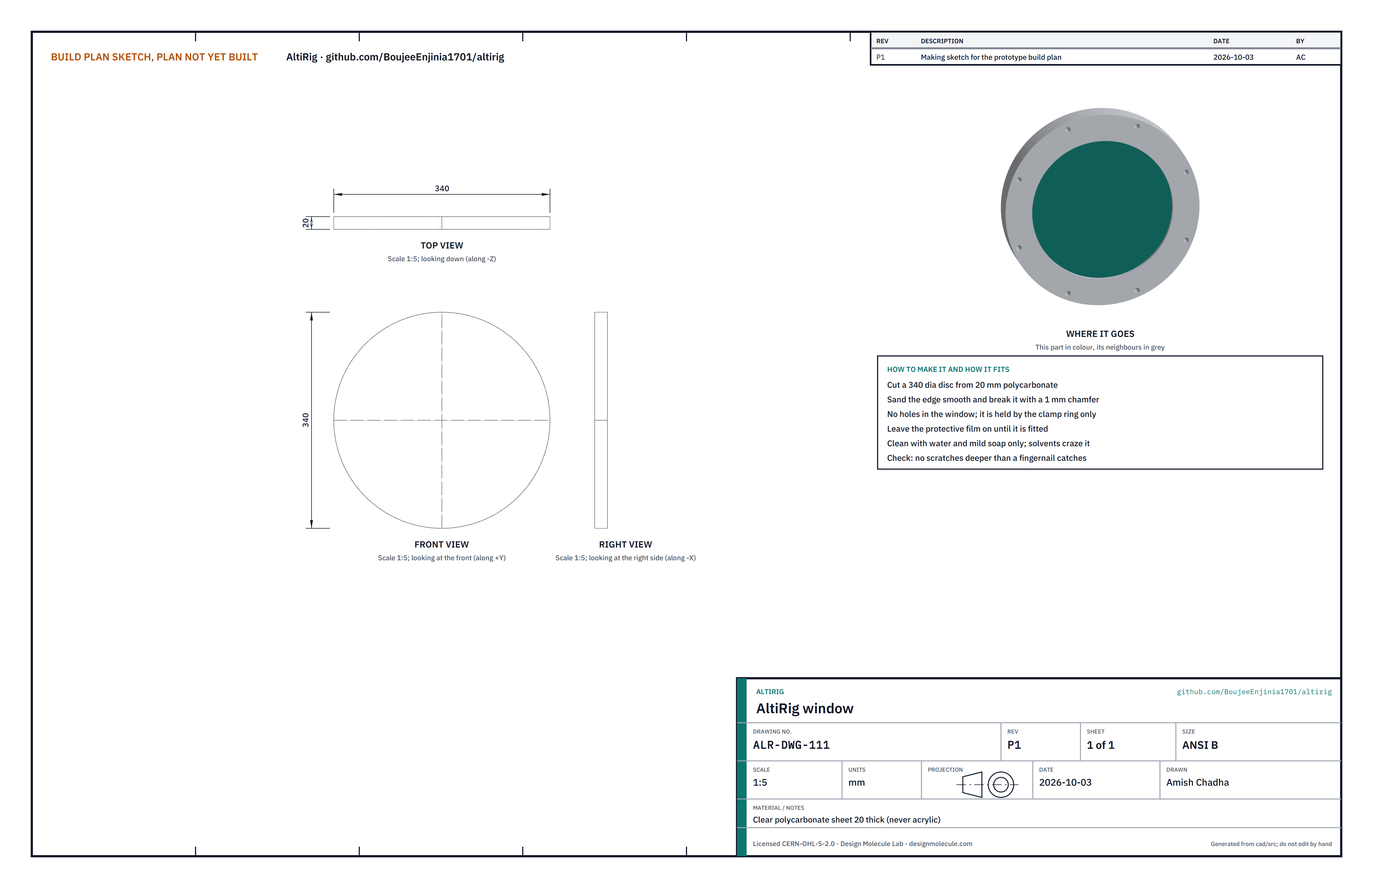
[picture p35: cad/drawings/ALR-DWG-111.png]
Figure 12. Making sketch, window


*Figure 12. Window (ALR-DWG-111).*

**What it is and what it is made from.** A 340 mm disc of clear polycarbonate sheet, 20 mm thick. Never acrylic or glass: they shatter.

**How to make it.** Cut the disc, sand the edge smooth and break it with a 1 mm chamfer. No holes. Leave the protective film on until fitted. Clean only with water and mild soap; solvents craze polycarbonate.

**How it fits the parts next to it.** It sits on a 6 mm EPDM ring gasket on the window flange and is held at its rim by the clamp ring (Figure 28). Under vacuum the air presses it onto the gasket.

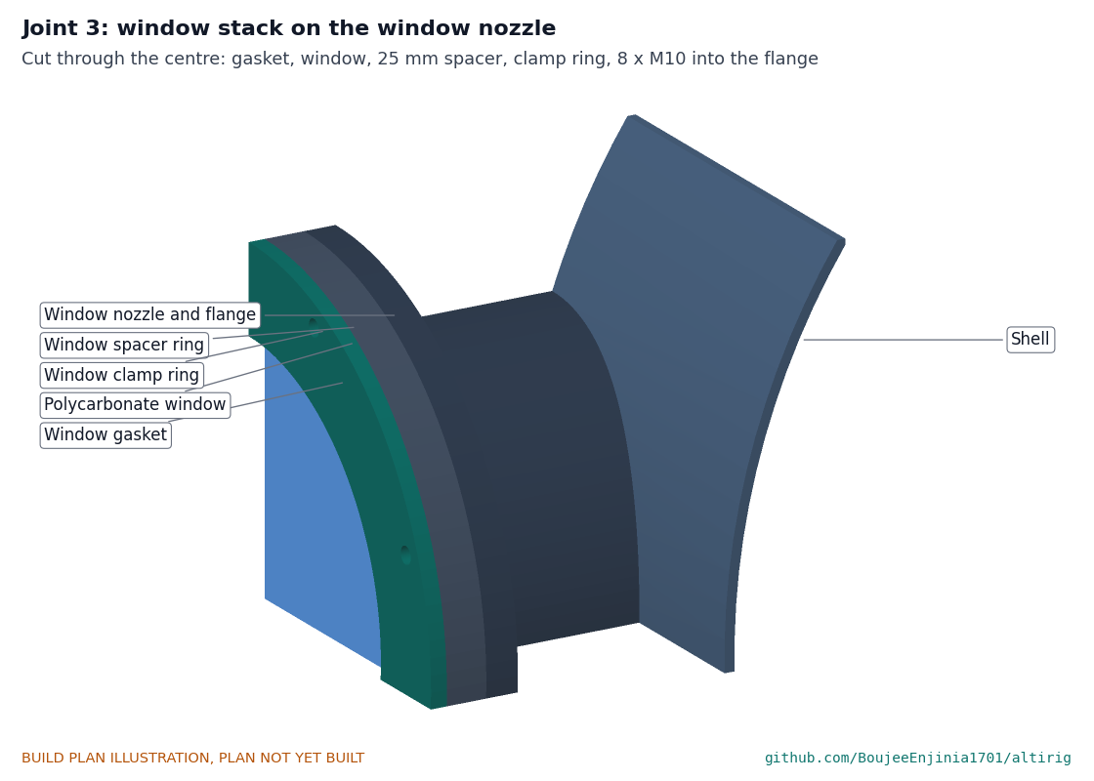
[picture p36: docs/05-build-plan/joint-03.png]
Figure 28. Joint 3, window stack


*Figure 28. Joint 3: flange, gasket, window, spacer ring and clamp ring, cut through the window's centre.*

**Check before moving on.** No scratch deep enough to catch a fingernail.

### 3.12 Window spacer and clamp rings

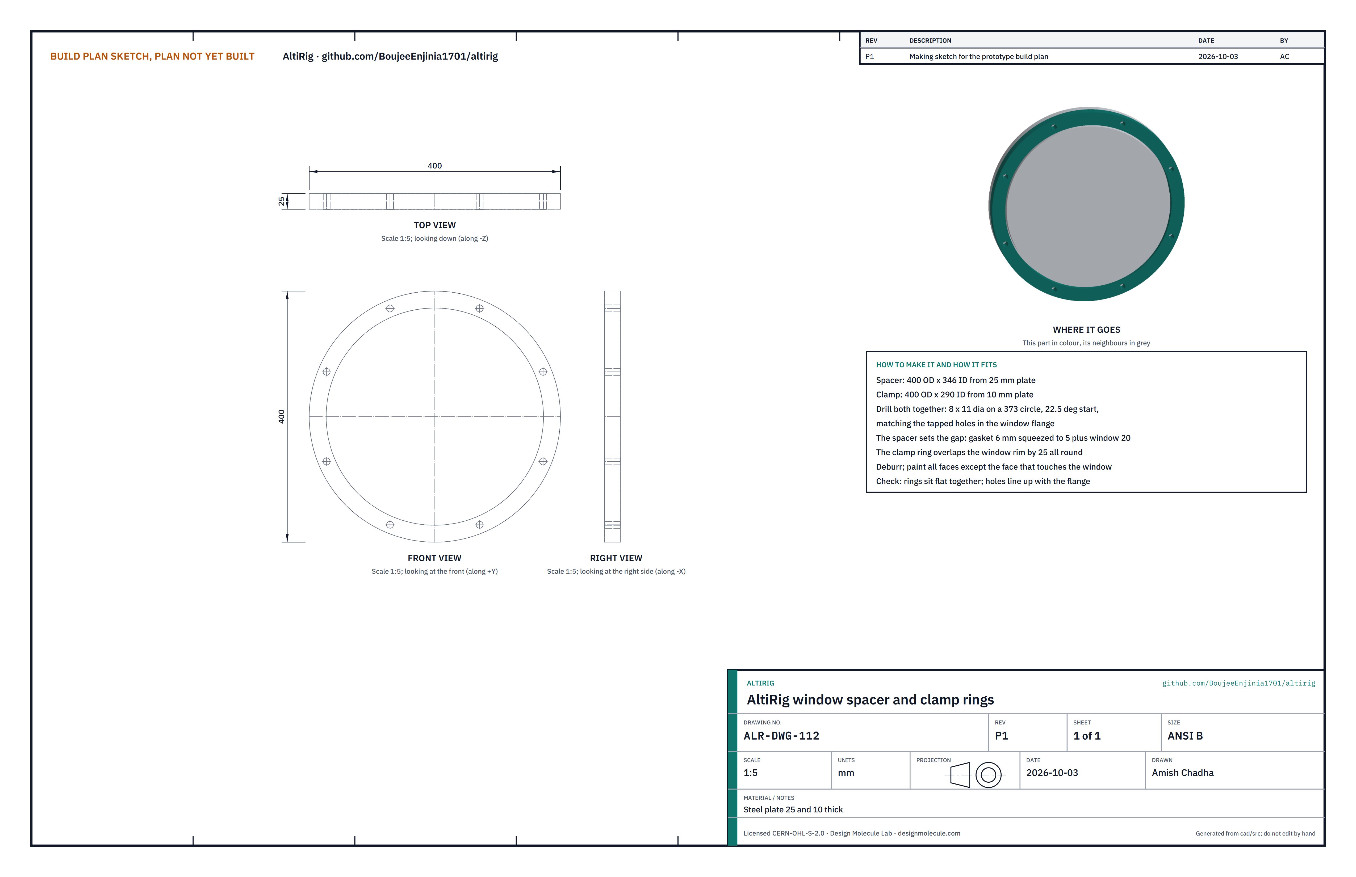
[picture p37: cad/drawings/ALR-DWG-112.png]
Figure 13. Making sketch, window rings


*Figure 13. Window spacer and clamp rings (ALR-DWG-112).*

**What it is and what it is made from.** A spacer ring of 25 mm plate, 400 mm outside and 346 mm inside, and a clamp ring of 10 mm plate, 400 mm outside and 290 mm inside.

**How to make it.** Cut both rings. Clamp them together and drill eight 11 mm holes on a 373 mm circle, the first 22.5° off the top, to match the flange. Deburr and paint, except the clamp ring's face that touches the window.

**How it fits the parts next to it.** The spacer sits on the flange outside the gasket and the window. It is as thick as the gasket squeezed to 5 mm plus the window, so tightening the clamp ring squeezes the gasket by 1 mm and no more. The clamp ring overlaps the window's rim by 25 mm.

**Check before moving on.** The rings sit flat together and the holes line up with the flange.

### 3.13 Feed-through plate

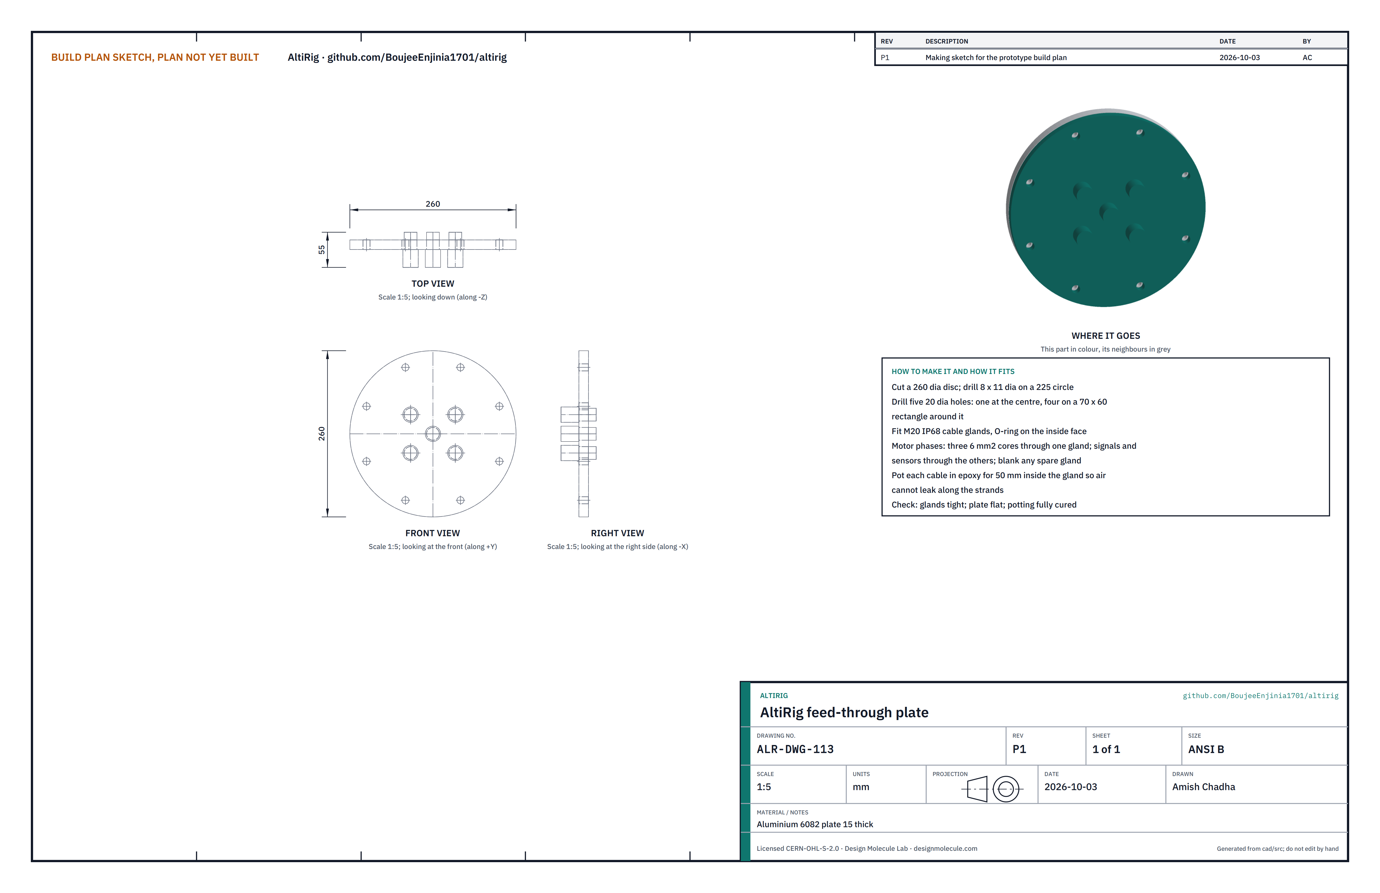
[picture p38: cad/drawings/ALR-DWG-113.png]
Figure 14. Making sketch, feed-through plate


*Figure 14. Feed-through plate (ALR-DWG-113).*

**What it is and what it is made from.** A 260 mm disc of 15 mm aluminium plate with five M20 IP68 cable glands.

**How to make it.**

1. Cut the disc and drill eight 11 mm holes on a 225 mm circle.
2. Drill five 20 mm holes: one at the centre and four on a 70 x 60 mm rectangle around it.
3. Fit the glands with their O-rings on the inside face. Run the three motor phase wires (6 mm2) through one gland and the signal and sensor cables through the others; blank any spare gland.
4. Pot each cable in epoxy for 50 mm inside its gland so air cannot leak along the strands.

**How it fits the parts next to it.** It bolts to the feed-through flange with eight M10 bolts on a 2 mm EPDM gasket (Figure 29).

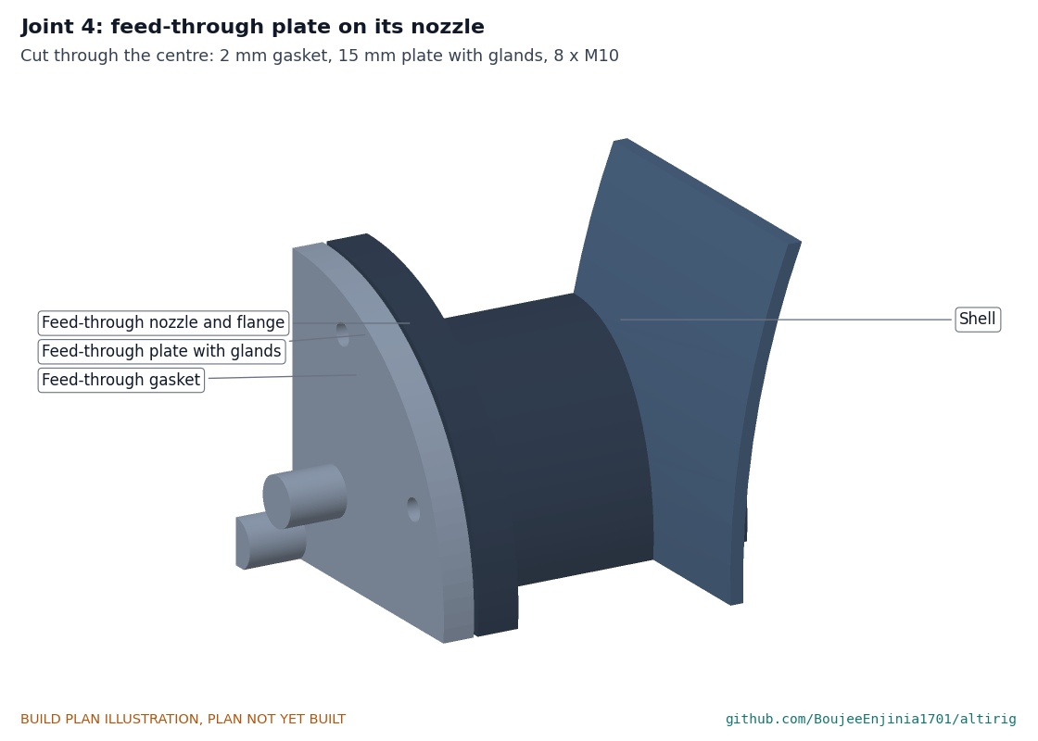
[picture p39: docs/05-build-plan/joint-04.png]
Figure 29. Joint 4, feed-through


*Figure 29. Joint 4: the plate on its gasket and flange, cut through the centre.*

**Check before moving on.** Glands tight; potting fully cured.

### 3.14 Deck plate

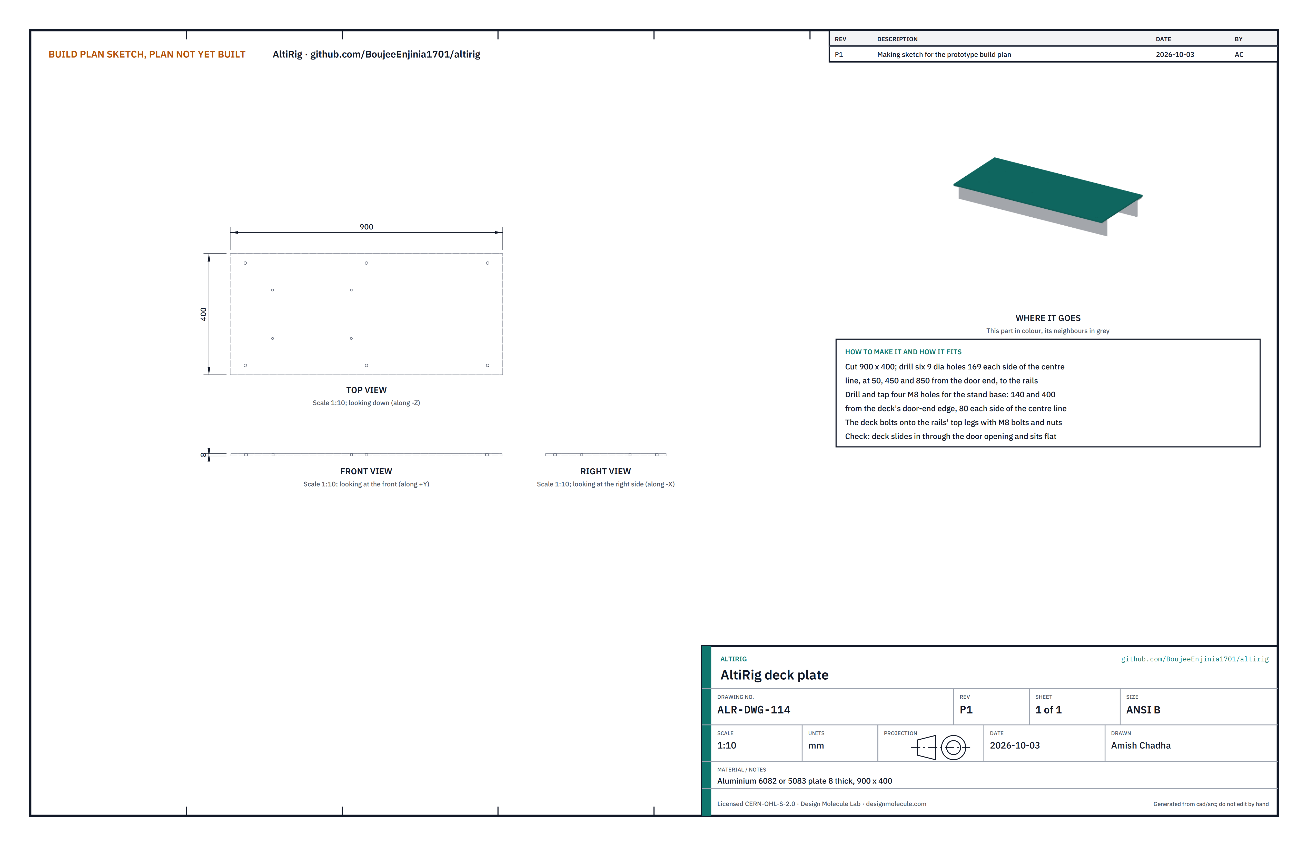
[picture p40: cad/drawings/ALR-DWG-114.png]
Figure 15. Making sketch, deck


*Figure 15. Deck plate (ALR-DWG-114).*

**What it is and what it is made from.** Aluminium plate 8 mm thick, 900 x 400 mm.

**How to make it.** Drill six 9 mm holes 169 mm each side of the centre line at 50, 450 and 850 mm from the door-end edge, to match the rails. Drill and tap four M8 holes for the stand base at 140 and 400 mm from the door-end edge, 80 mm each side of the centre line.

**How it fits the parts next to it.** It slides in through the door onto the rails' top legs and is bolted down with six M8 bolts and nuts (Figure 32).

**Check before moving on.** The deck sits flat on both rails.

### 3.15 Baffle plate

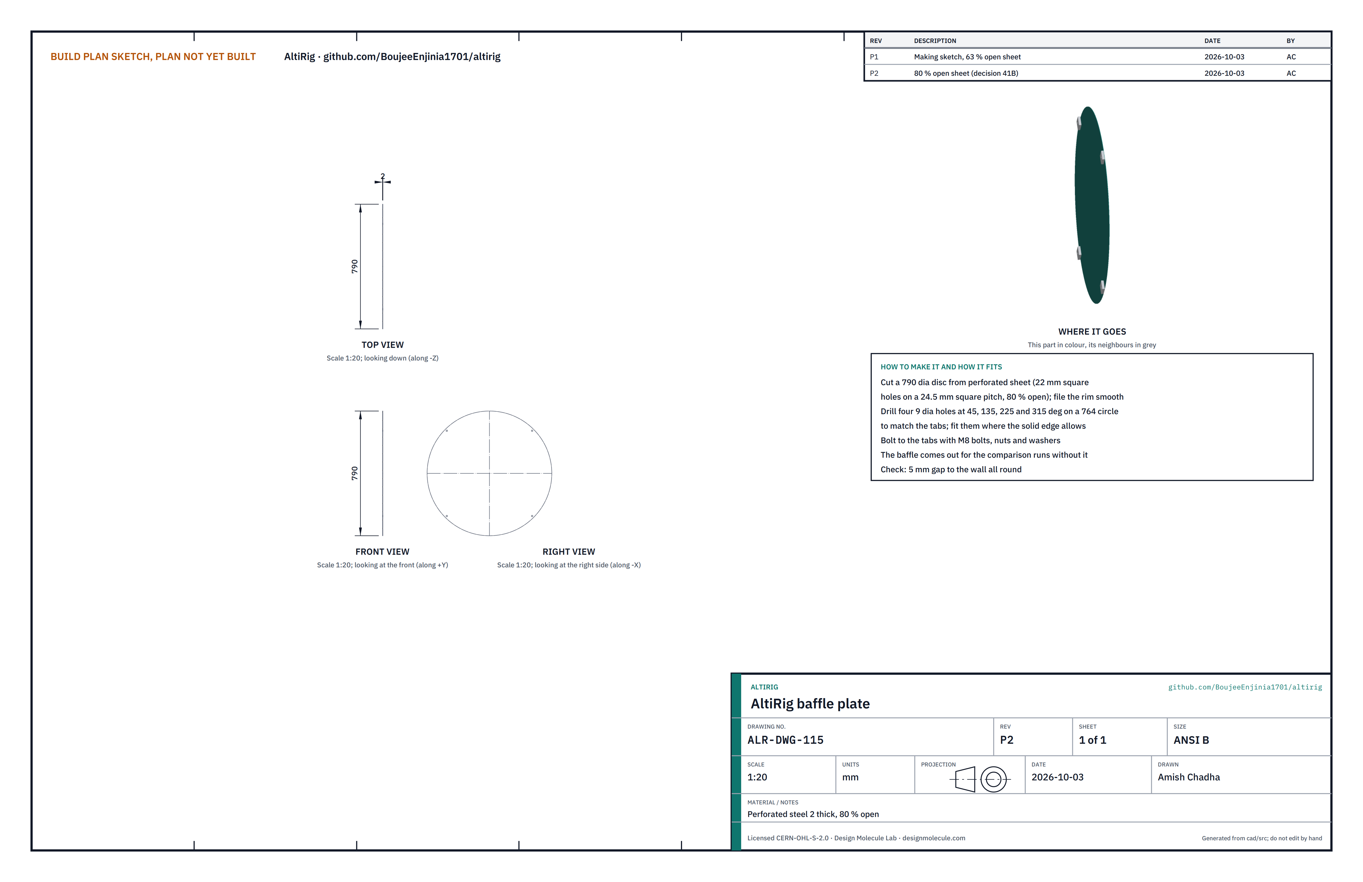
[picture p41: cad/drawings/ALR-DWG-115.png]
Figure 16. Making sketch, baffle


*Figure 16. Baffle plate (ALR-DWG-115).*

**What it is and what it is made from.** A 790 mm disc of 2 mm perforated steel with 22 mm square holes on a 24.5 mm square pitch, so 80 % of it is open and the bars between the holes are 2.5 mm wide (Amish's decision 41B). It weighs about 1.5 kg.

**How to make it.** Cut the disc and file the rim smooth, removing any sharp part-holes or loose slivers at the edge. Drill four 9 mm holes at 45°, 135°, 225° and 315° on a 764 mm circle to match the tabs.

**How it fits the parts next to it.** It bolts to the four tabs with M8 bolts, 590 mm downstream of the propeller, with a 5 mm gap to the wall (Figure 35). It is taken out for the comparison runs without it.

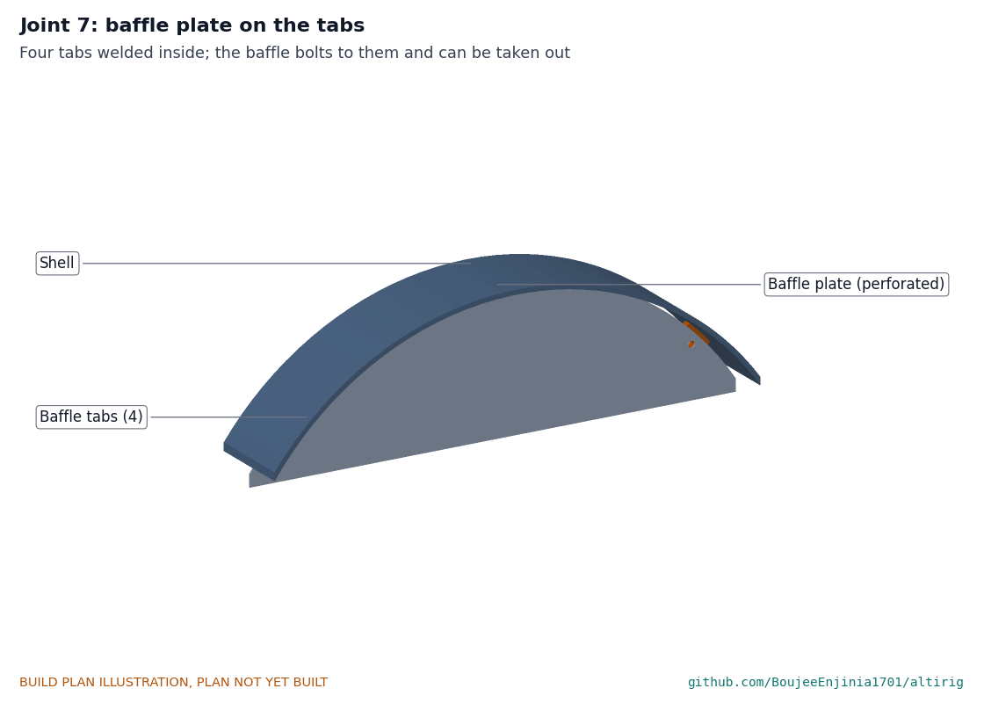
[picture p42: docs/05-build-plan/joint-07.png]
Figure 35. Joint 7, baffle on its tabs


*Figure 35. Joint 7: the baffle bolted to a tab welded inside the shell.*

**Check before moving on.** The gap to the wall is even all round.

### 3.16 Stand base plate

Figure 17. Making sketch, stand base

*Figure 17. Stand base plate (ALR-DWG-116).*

**What it is and what it is made from.** Aluminium plate 12 mm thick, 300 x 200 mm.

**How to make it.** Drill four 9 mm holes 20 mm in from each corner, counterbored for the M8 screws into the deck. Tap M5 holes for the two lower flexure clamps (centres 50 mm and 250 mm from the door-end edge), the anchor block and the speed sensor post. Face the top flat.

**How it fits the parts next to it.** It is screwed to the deck; the lower clamps, the anchor block and the speed post screw onto it (Figure 33).

**Check before moving on.** Flat to 0.1 mm across the clamp positions.

### 3.17 Flexure leaves and clamps

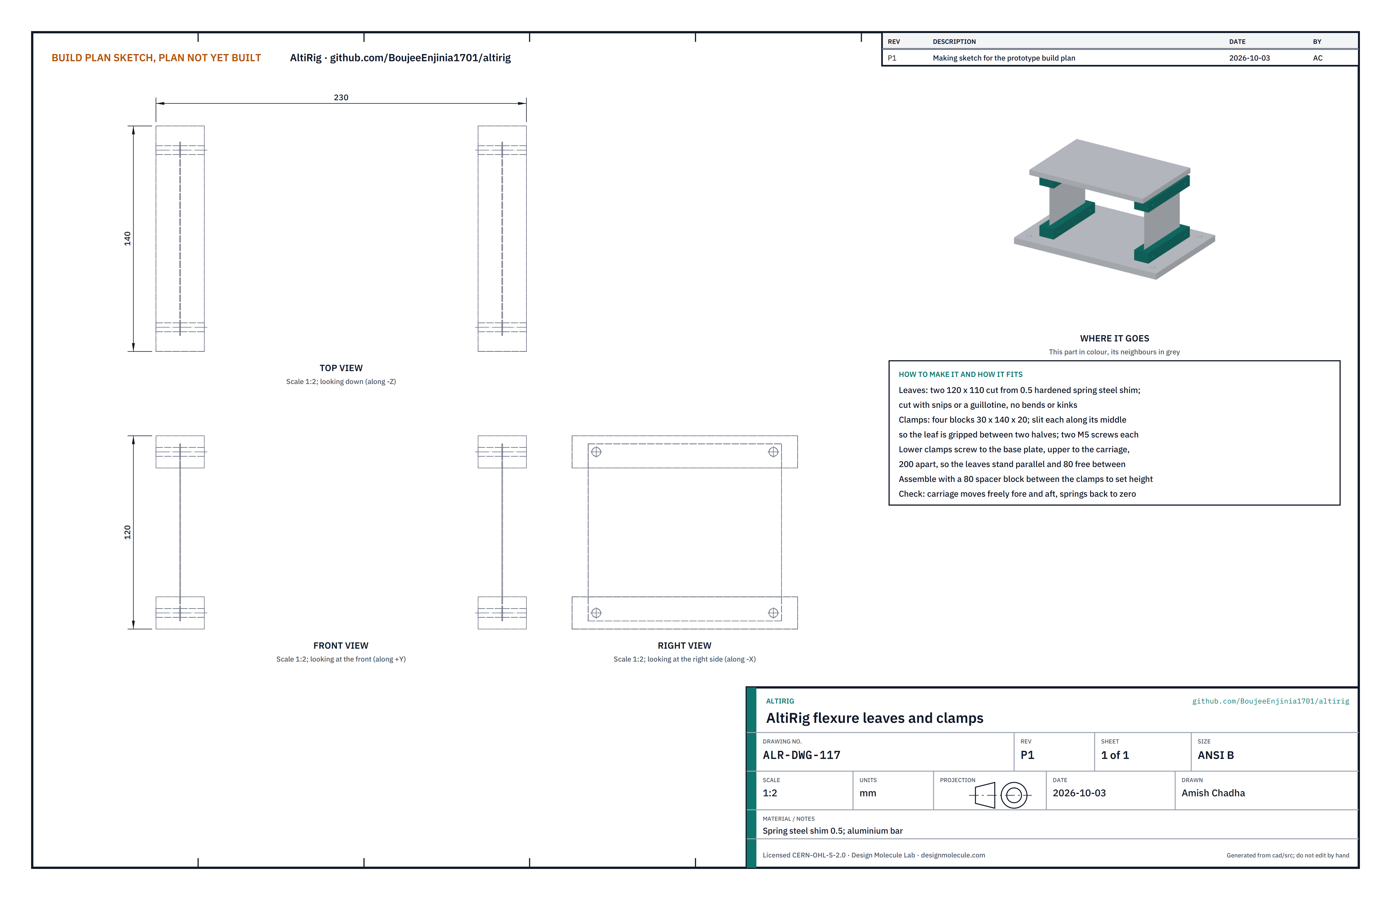
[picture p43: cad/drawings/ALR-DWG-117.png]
Figure 18. Making sketch, flexures


*Figure 18. Flexure leaves and clamps (ALR-DWG-117).*

**What it is and what it is made from.** Two leaves 120 x 110 mm cut from 0.5 mm hardened spring steel shim, and four aluminium clamp blocks 30 x 140 x 20 mm.

**How to make it.**

1. Cut the leaves with snips or a guillotine. Do not bend or kink them.
2. Slit each clamp block along its middle so a leaf is gripped between the two halves; drill for two M5 screws.

**How it fits the parts next to it.** The two lower clamps screw to the base plate 200 mm apart; the two upper clamps screw to the underside of the carriage. Each leaf is gripped 15 mm deep at top and bottom, with 80 mm free between the clamps, so the leaves stand parallel and the carriage can move a fraction of a millimetre along the axis (Figure 33). Set the height with an 80 mm spacer block between the clamps while tightening.

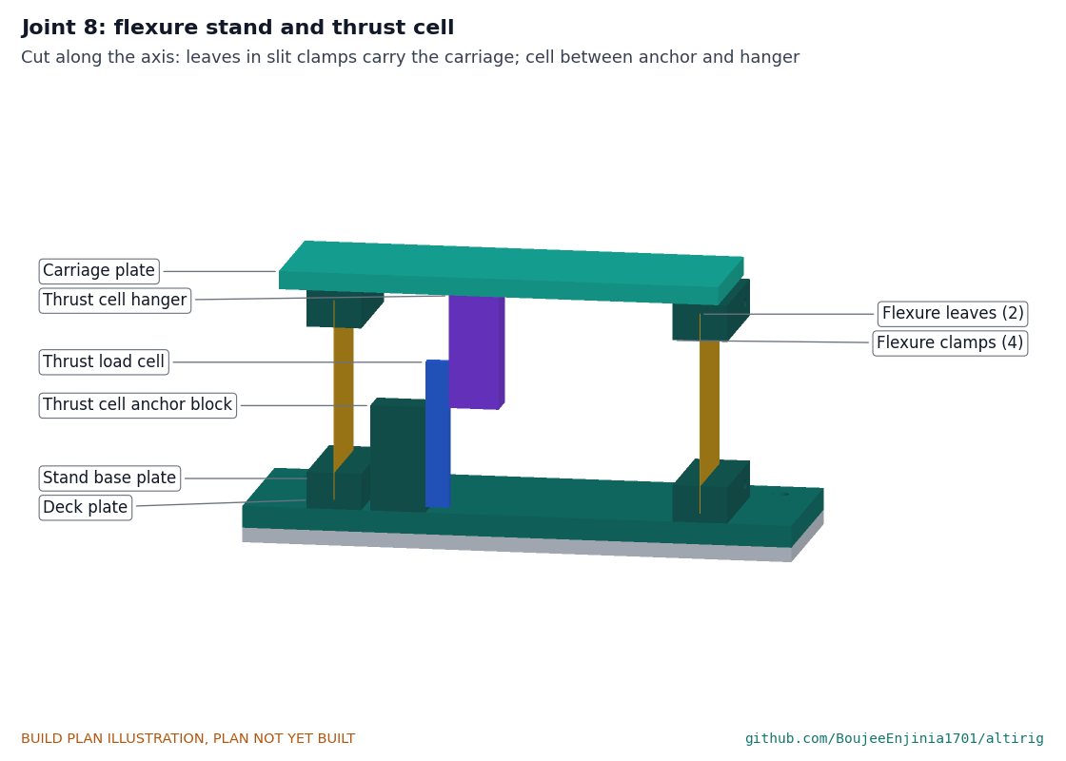
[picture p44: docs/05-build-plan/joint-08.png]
Figure 33. Joint 8, flexure stand and thrust cell


*Figure 33. Joint 8: the leaves in their clamps between the base plate and the carriage, and the thrust cell between the anchor and the hanger, cut along the axis.*

**Check before moving on.** The carriage moves freely along the axis and springs back to the same place.

### 3.18 Thrust cell anchor block and hanger

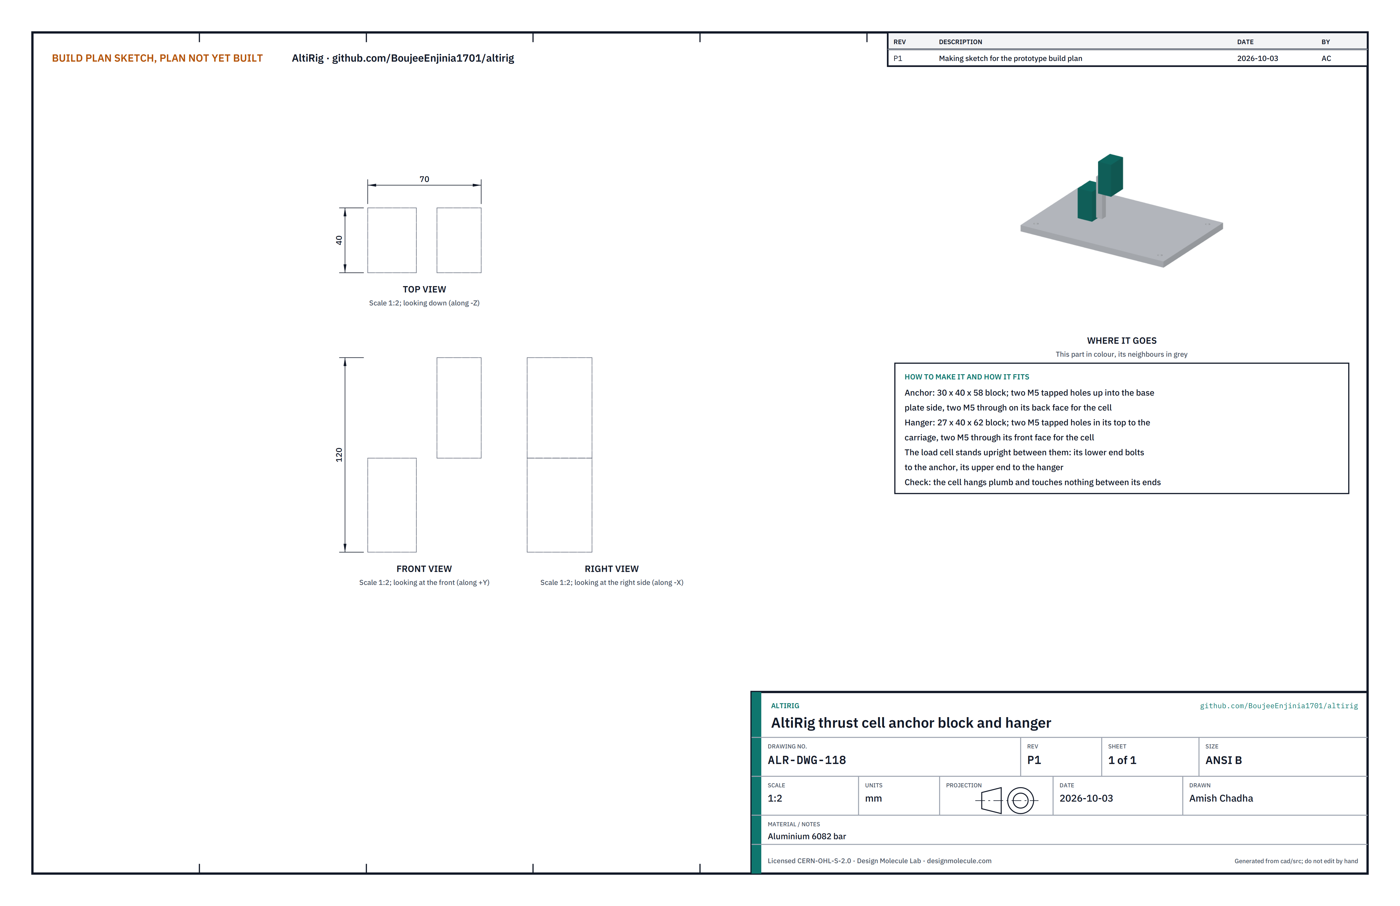
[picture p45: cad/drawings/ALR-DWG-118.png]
Figure 19. Making sketch, anchor and hanger


*Figure 19. Anchor block and hanger (ALR-DWG-118).*

**What it is and what it is made from.** Two blocks of aluminium bar: the anchor 30 x 40 x 58 mm and the hanger 27 x 40 x 62 mm.

**How to make it.** Drill and tap each for two M5 screws to its plate (the anchor down into the base plate, the hanger up into the carriage) and two M5 screws to the load cell.

**How it fits the parts next to it.** The 10 kg bar load cell stands upright between them: its lower end is screwed to the anchor's face and its upper end to the hanger's face. The propeller's thrust pushes the carriage, which pushes the top of the cell (Figure 33).

**Check before moving on.** The cell hangs plumb and touches nothing between its two ends.

### 3.19 Carriage plate

Figure 20. Making sketch, carriage

*Figure 20. Carriage plate (ALR-DWG-119).*

**What it is and what it is made from.** Aluminium plate 10 mm thick, 240 x 160 mm.

**How to make it.** Drill for the two upper clamps (M5 clearance), the hanger (two M5) and the torque head housing (four M6).

**How it fits the parts next to it.** It hangs on the two leaves through the upper clamps and carries the torque head.

**Check before moving on.** Flat; no screw head proud on its underside near the cell.

### 3.20 Torque head

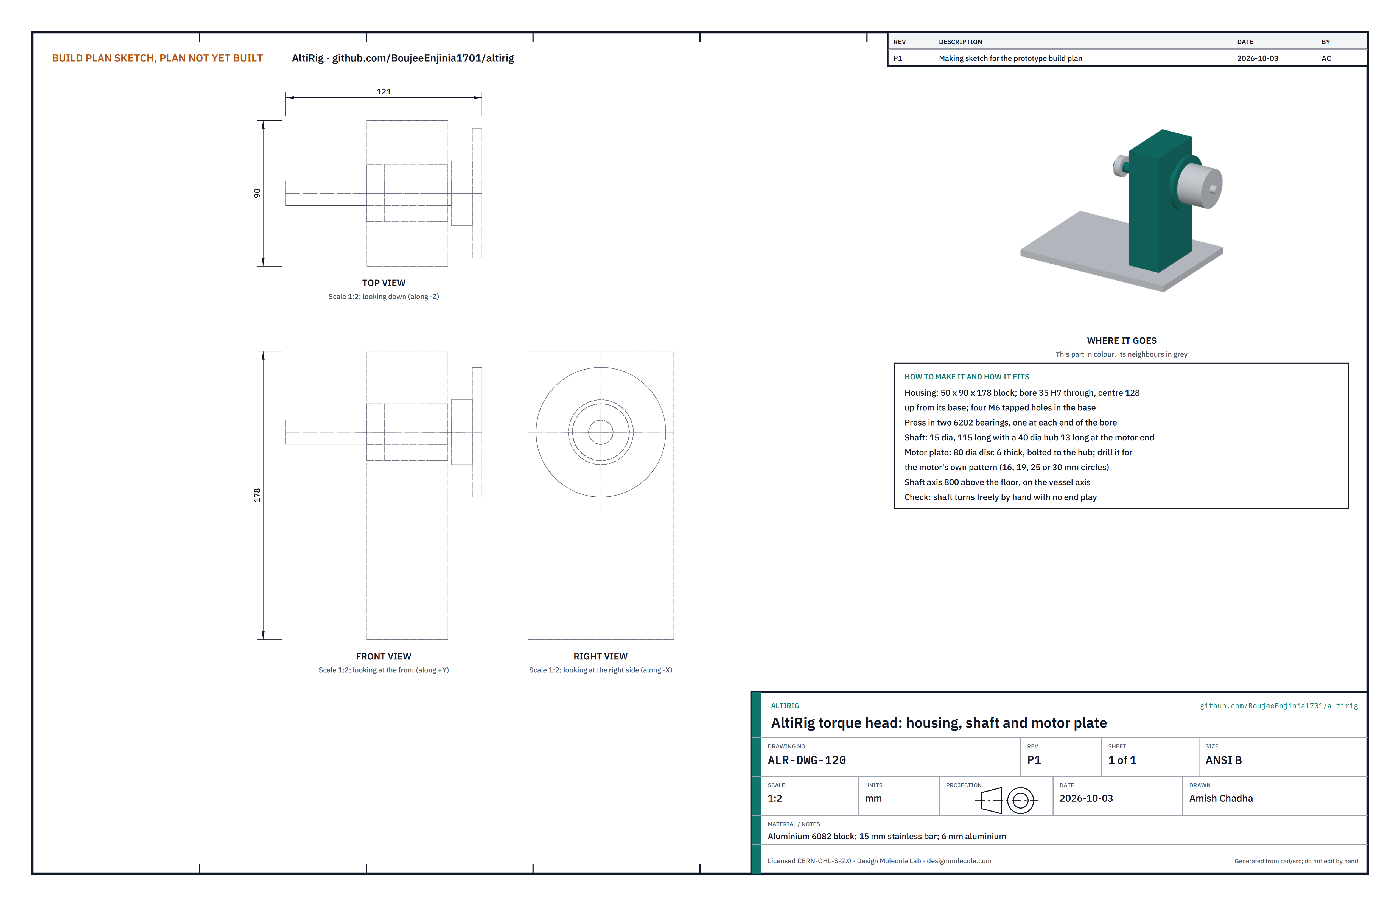
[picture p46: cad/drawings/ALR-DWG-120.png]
Figure 21. Making sketch, torque head


*Figure 21. Torque head: housing, bearings, shaft and motor plate (ALR-DWG-120).*

**What it is and what it is made from.** An aluminium housing 50 x 90 x 178 mm, two 6202 sealed bearings, a 15 mm stainless steel shaft 115 mm long with a 40 mm hub, and an 80 mm aluminium motor plate 6 mm thick.

**How to make it.**

1. Bore the housing 35 mm (a light press fit for the bearings) right through, the bore's centre 128 mm above its base. Tap four M6 holes in its base.
2. Press a bearing into each end of the bore.
3. Turn the shaft with its hub at the motor end; tap the hub for the motor plate.
4. Drill the motor plate for the motor's own pattern (16, 19, 25 or 30 mm circles) and screw it to the hub.

**How it fits the parts next to it.** The housing screws to the carriage with the shaft on the vessel's axis, 800 mm above the floor. The motor screws to the motor plate. The torque arm clamps to the shaft's other end (Figure 34).

**Check before moving on.** The shaft turns freely by hand with no end play.

### 3.21 Torque arm and cell bracket

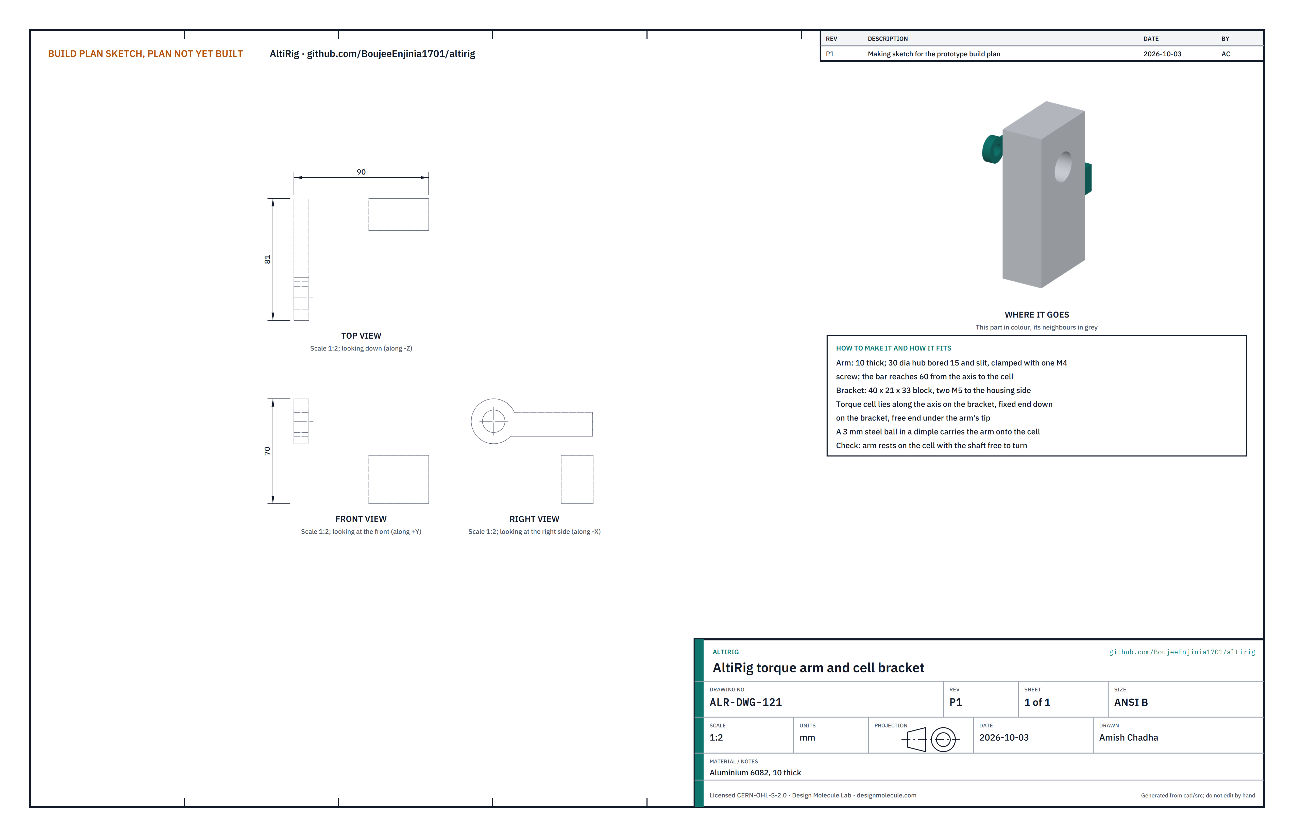
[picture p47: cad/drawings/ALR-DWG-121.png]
Figure 22. Making sketch, torque arm


*Figure 22. Torque arm and cell bracket (ALR-DWG-121).*

**What it is and what it is made from.** An aluminium arm 10 mm thick with a 30 mm hub bored 15 mm and slit, reaching 60 mm from the axis; and an aluminium bracket 40 x 21 x 33 mm.

**How to make it.** Bore and slit the arm's hub and drill it for one M4 clamp screw. Drill the bracket for two M5 screws into the housing's side and two M5 screws for the cell. Press a 3 mm steel ball into a dimple under the arm's tip.

**How it fits the parts next to it.** The bracket screws to the housing's side. The 5 kg bar load cell lies along the axis with its fixed end screwed down on the bracket and its free end under the arm's tip. The arm, clamped to the shaft, rests on the cell through the ball, so the motor's reaction torque presses on the cell (Figure 34).

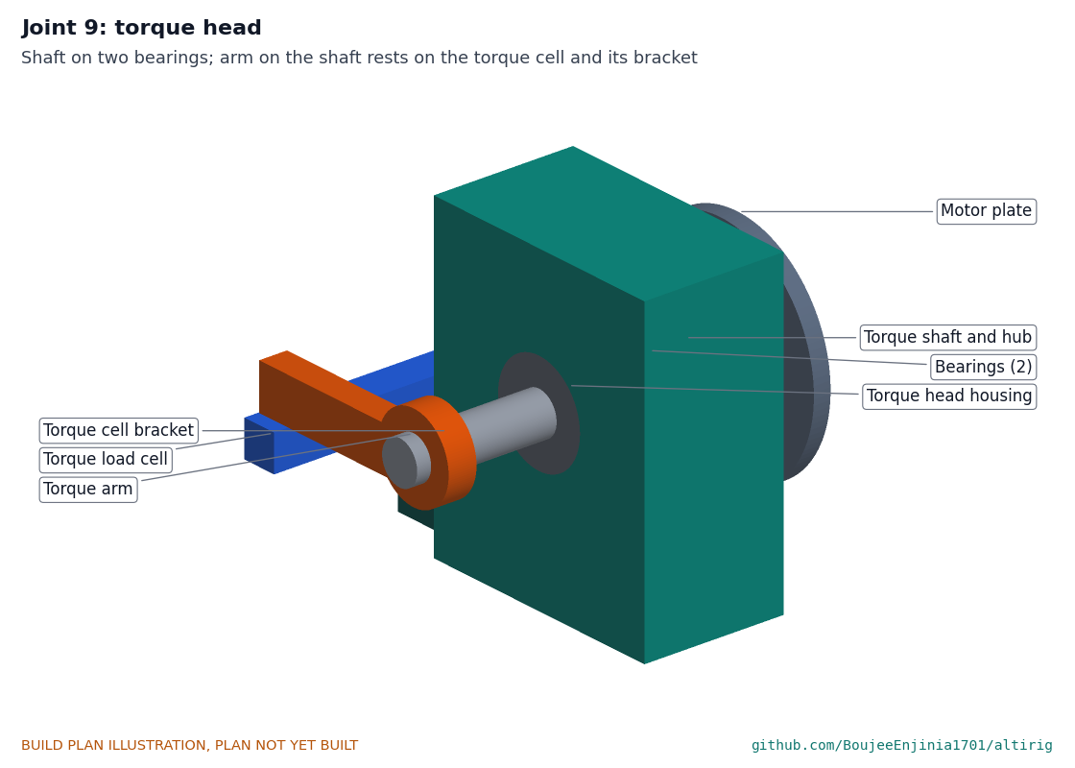
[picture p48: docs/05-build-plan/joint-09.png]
Figure 34. Joint 9, torque head


*Figure 34. Joint 9: shaft on two bearings in the housing, the arm on the shaft resting on the torque cell, the cell on its bracket.*

**Check before moving on.** The arm rests on the cell with the shaft still free to turn.

### 3.22 Speed sensor post

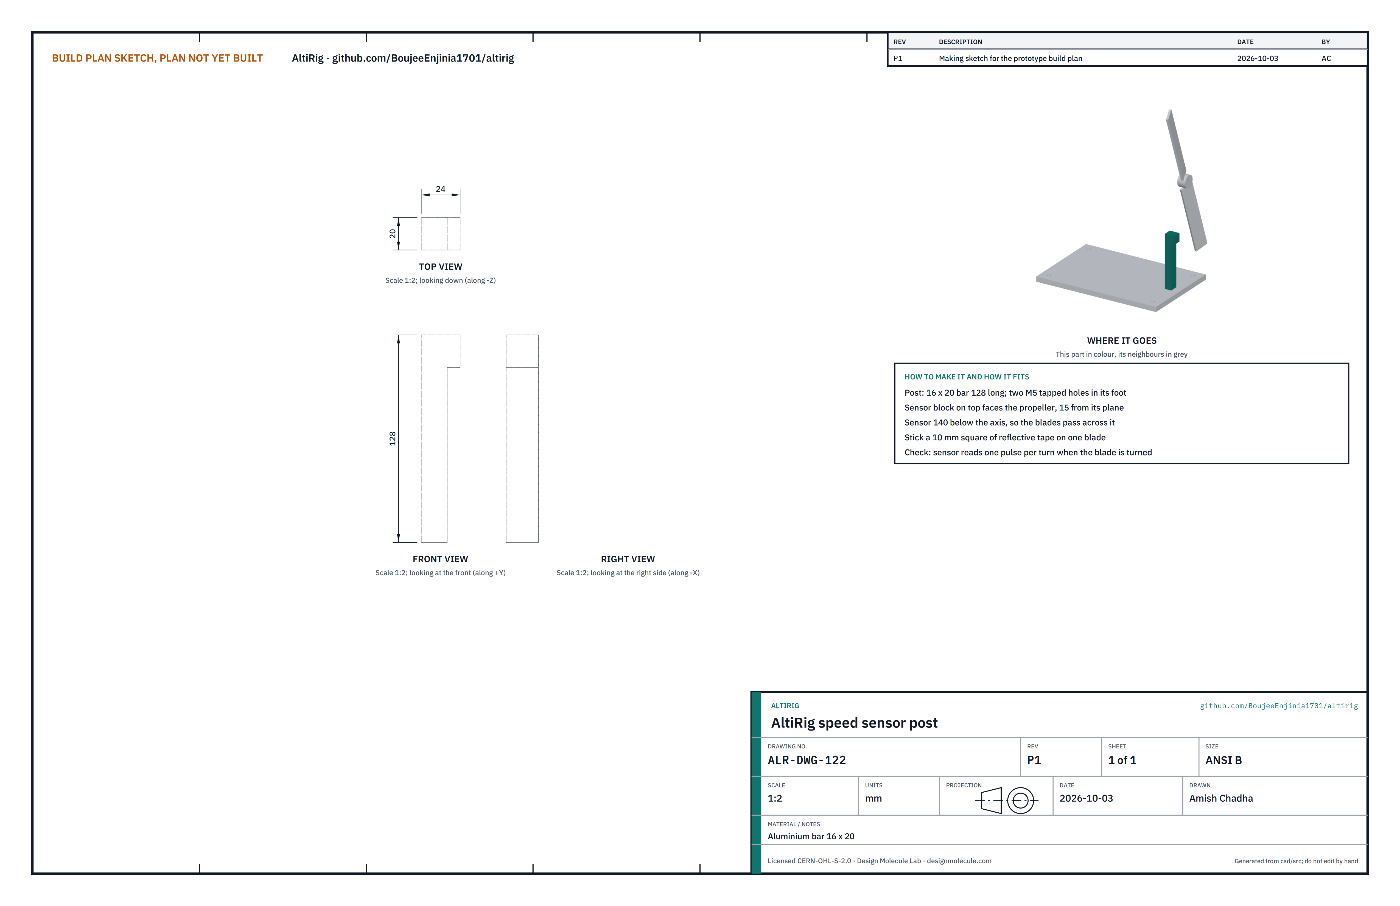
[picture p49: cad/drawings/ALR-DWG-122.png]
Figure 23. Making sketch, speed sensor post


*Figure 23. Speed sensor post (ALR-DWG-122).*

**What it is and what it is made from.** A 16 x 20 mm aluminium bar 128 mm long with a block on top for the optical sensor.

**How to make it.** Cut, drill and tap two M5 holes in the foot; screw the sensor to the top block.

**How it fits the parts next to it.** It screws to the base plate so the sensor faces the propeller, 15 mm from its plane and 140 mm below the axis. A 10 mm square of reflective tape on one blade gives one pulse a turn.

**Check before moving on.** Turning the propeller by hand gives one pulse a turn.

### 3.23 Bought components

- **Dished heads (2):** 2:1 semi-ellipsoidal carbon steel tank heads, 813 mm outside diameter, 6.35 mm, 40 mm straight skirt, bought second-hand or as overstock. Before buying, check that the outside diameter matches the pipe, the wall is 5.9 mm or more and the skirt is 40 mm long and round. One is welded to the rear of the shell; one becomes the door.
- **Gaskets:** closed-cell EPDM sponge strip 6 x 45 mm, about 2.8 m, glued to the shell ring's face with contact adhesive, joined with a scarf cut at the bottom; solid EPDM sheet 6 mm and 2 mm cut to rings for the window and the feed-through.
- **Latch clamps (3):** adjustable latch clamps holding at least 3 kN, bolted to the back of the shell ring at the top, the window side and the bottom.
- **Valve manifold:** an adjustable vacuum relief valve set to open at 55 kPa below atmosphere; a 63 mm vacuum gauge; a normally-open solenoid bleed valve with a needle valve; a 1/2 in manual vent valve; a 1 in isolation ball valve and pump port. Assembled on one block with thread sealant and bolted to the stub flange with four M8 screws and a 2 mm gasket (Figure 27).
- **Load cells:** bending-beam bar cells 12.7 x 12.7 x 80 mm, C3 class or better: 10 kg for thrust, 5 kg for torque, with two 24-bit amplifiers.
- **Air sensors:** two barometric sensors accurate to 50 Pa absolute, one humidity sensor and two class A platinum probes, in a vented printed box on the deck.
- **Vacuum pump and hose:** the host lab's single-stage rotary vane pump, 170 L/min and no less than 140 L/min, with a thermal overload and an oil-mist filter; a bought 25 mm bore wire-reinforced hose with clamps and an adapter to the pump inlet. A smaller pump takes longer than 5 minutes to reach 54 kPa.
- **Motor power supply:** the host lab's DC power supply, 24 V adjustable from 20 to 28 V and at least 1,500 W, with overcurrent protection. It stands beside the cabinet and is switched through the cabinet's interlocked motor contactor and emergency stop, never connected straight to the speed controller.
- **Control cabinet:** floor-standing steel enclosure with a 30 mA residual current device on the mains inlet, the motor contactor that switches the host lab's motor supply, the speed controller and power sensor, the controller and logger, the emergency stop and contactors, the door interlock switch (on the top latch) and the arming key switch.
- **Motor and propeller under test:** an example 6S motor for 15 in propellers and a 15 x 5 in carbon propeller; users bring their own.

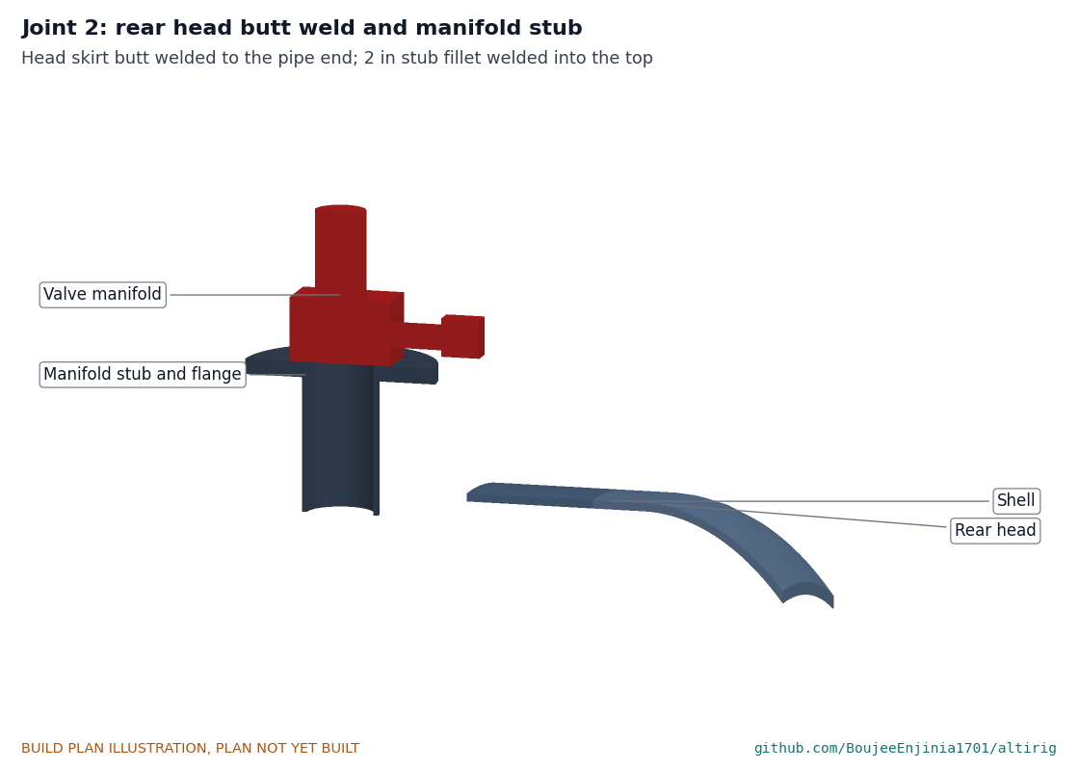
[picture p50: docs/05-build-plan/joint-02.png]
Figure 27. Joint 2, rear head and manifold stub


*Figure 27. Joint 2: the rear head's skirt butt welded to the pipe end, and the manifold stub with the manifold on top.*

## 4. Putting it together

Steps 1 to 6 are welding shop work; steps 7 to 20 are done in the lab. Fitted parts are grey; the part being fitted is in colour with an arrow showing the way it goes in.

### Step 1: flange ring onto the shell end

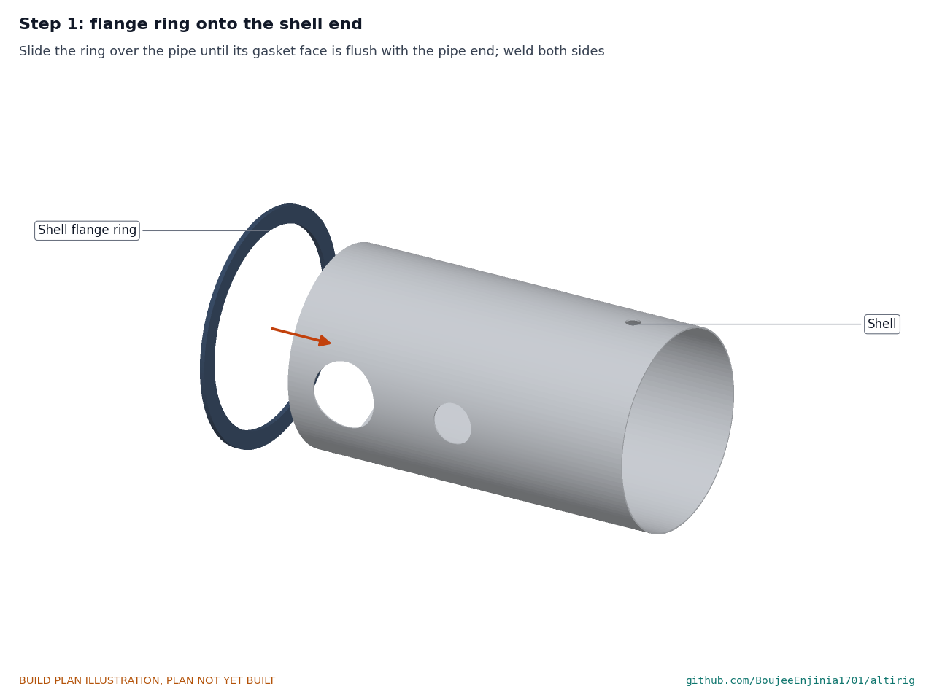
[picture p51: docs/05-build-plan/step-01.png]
Step 1


Slide the shell ring over the door end until its gasket face is flush with the pipe end. Fillet weld both sides, 6 mm leg, in short balanced runs. **Hold point:** check the face is flat to 1 mm before going on.

### Step 2: rear head

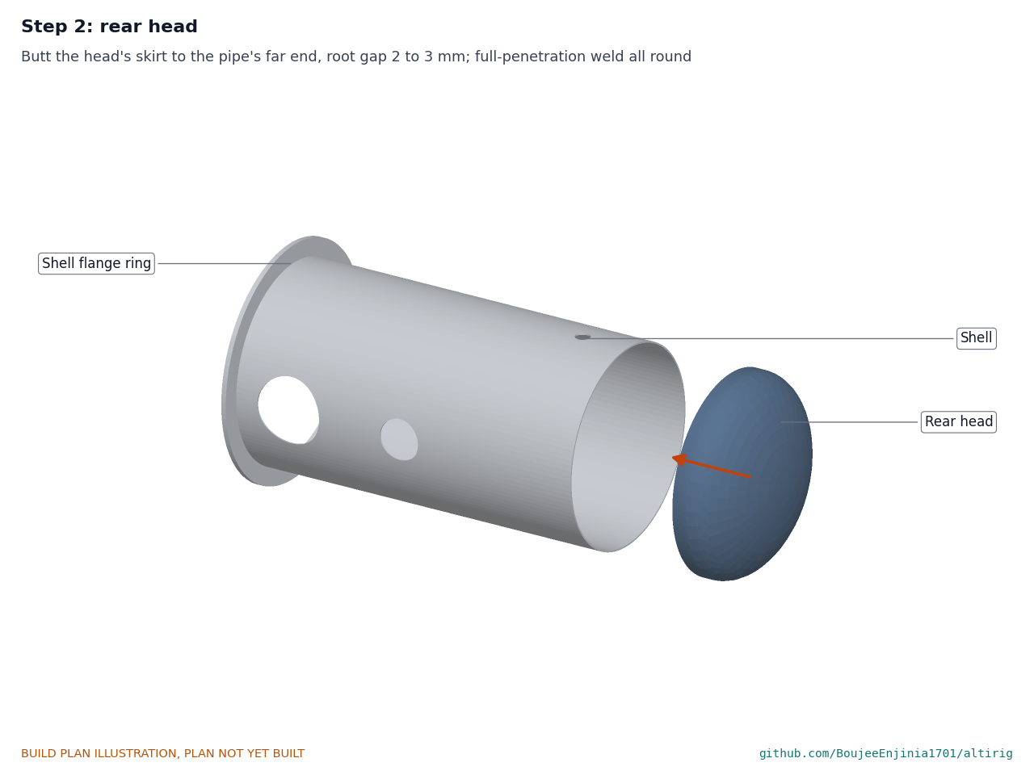
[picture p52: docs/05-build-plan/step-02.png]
Step 2


Butt the rear head's skirt against the far end of the pipe with a 2 to 3 mm root gap, tack at four points, then weld all round with full penetration. Grind the inside flush. **Hold point:** the weld is continuous all round; a broken weld here halves the shell's strength (ALR-CAL-001, section B).

### Step 3: nozzles into the shell

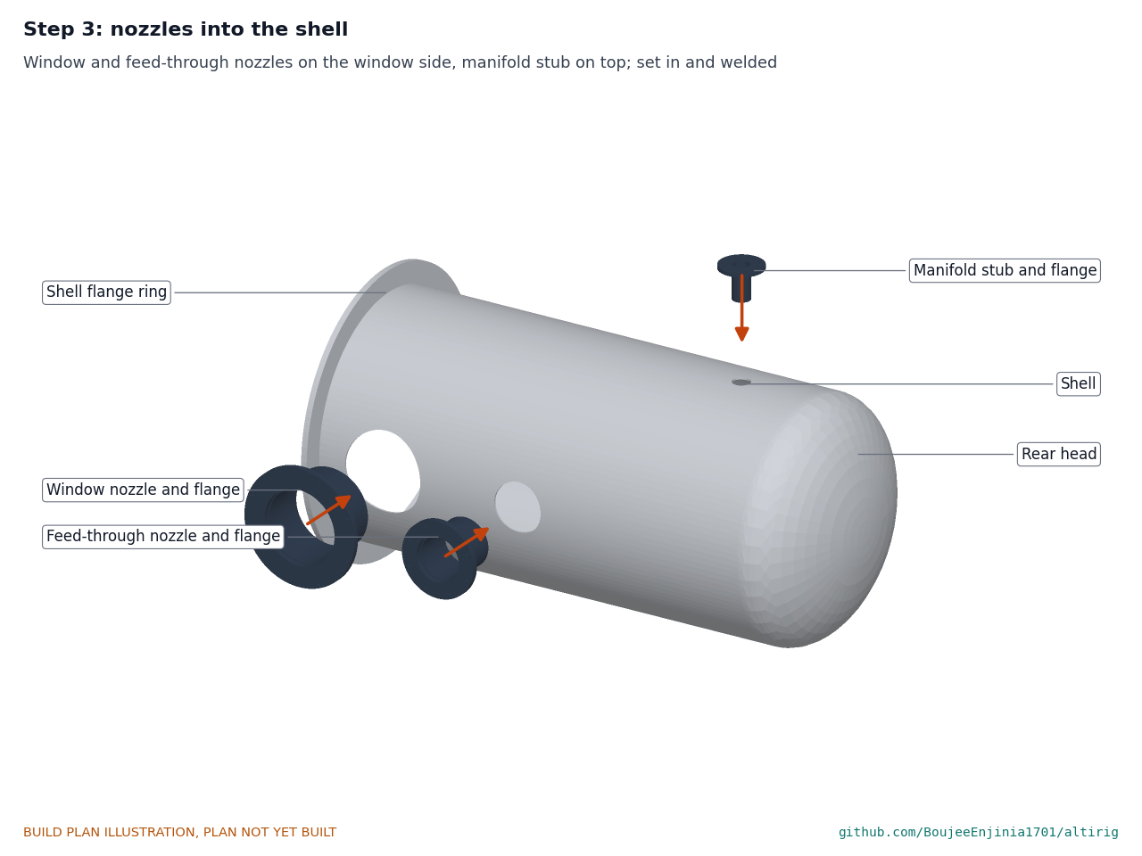
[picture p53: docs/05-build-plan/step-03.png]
Step 3


Set the window and feed-through nozzles into their holes on the window side with their flanges 520 mm and 500 mm from the axis, and the manifold stub on the top line. Weld each stub outside and inside.

### Step 4: saddles

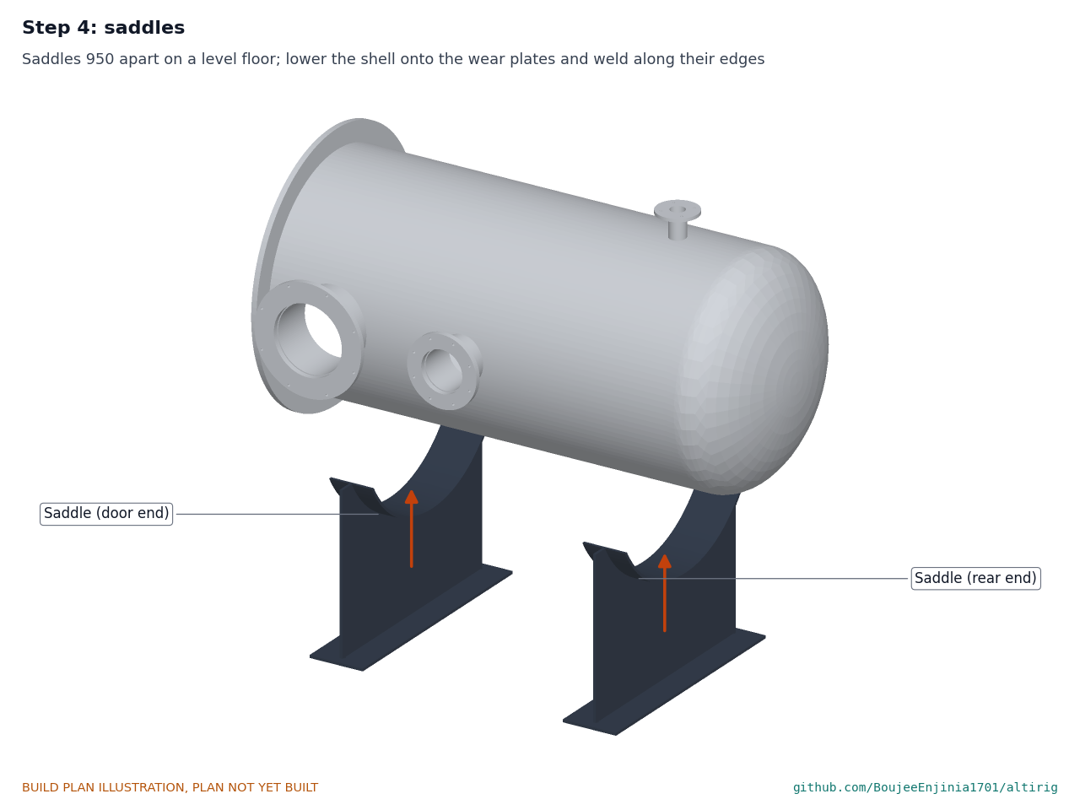
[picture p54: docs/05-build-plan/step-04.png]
Step 4


Stand the saddles on a level floor 950 mm apart (centres 300 mm and 1,250 mm from the shell ring face). Lower the shell onto the wear plates with the window side toward the operator's side of the room, and weld the wear plates to the shell along both edges.

### Step 5: deck rails and baffle tabs inside

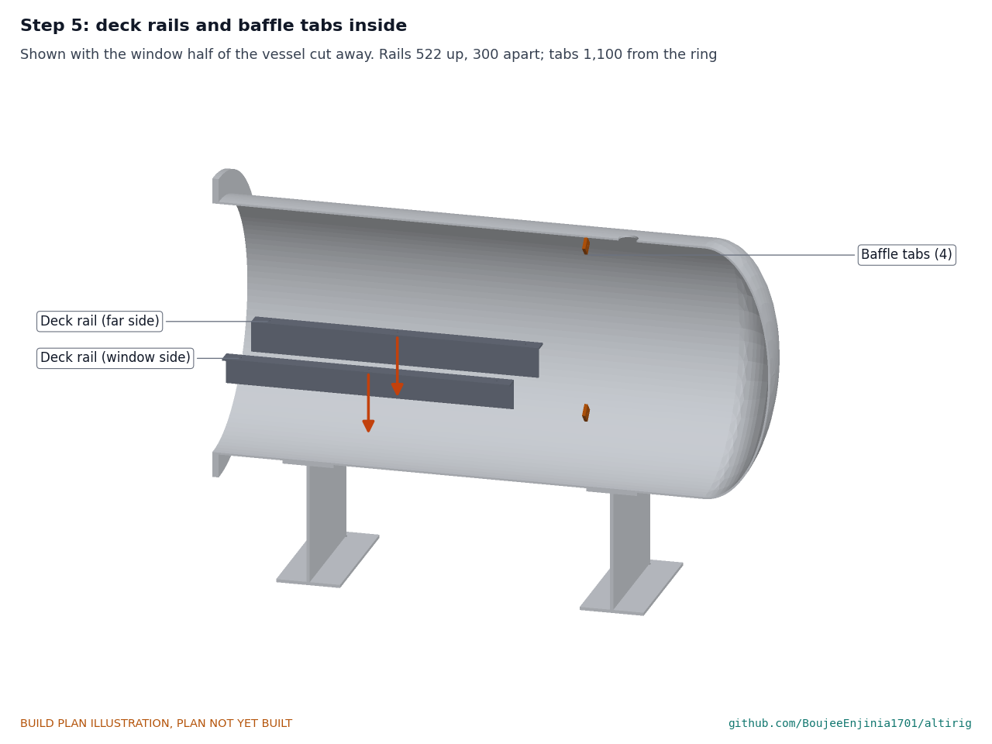
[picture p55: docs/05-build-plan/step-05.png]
Step 5


Shown with the window half of the vessel cut away. Weld the two rails inside, top legs 522 mm above the floor and 300 mm apart, and the four tabs 1,100 mm from the shell ring face. Grind away spatter inside.

### Step 6: door, ring and lugs onto the second head

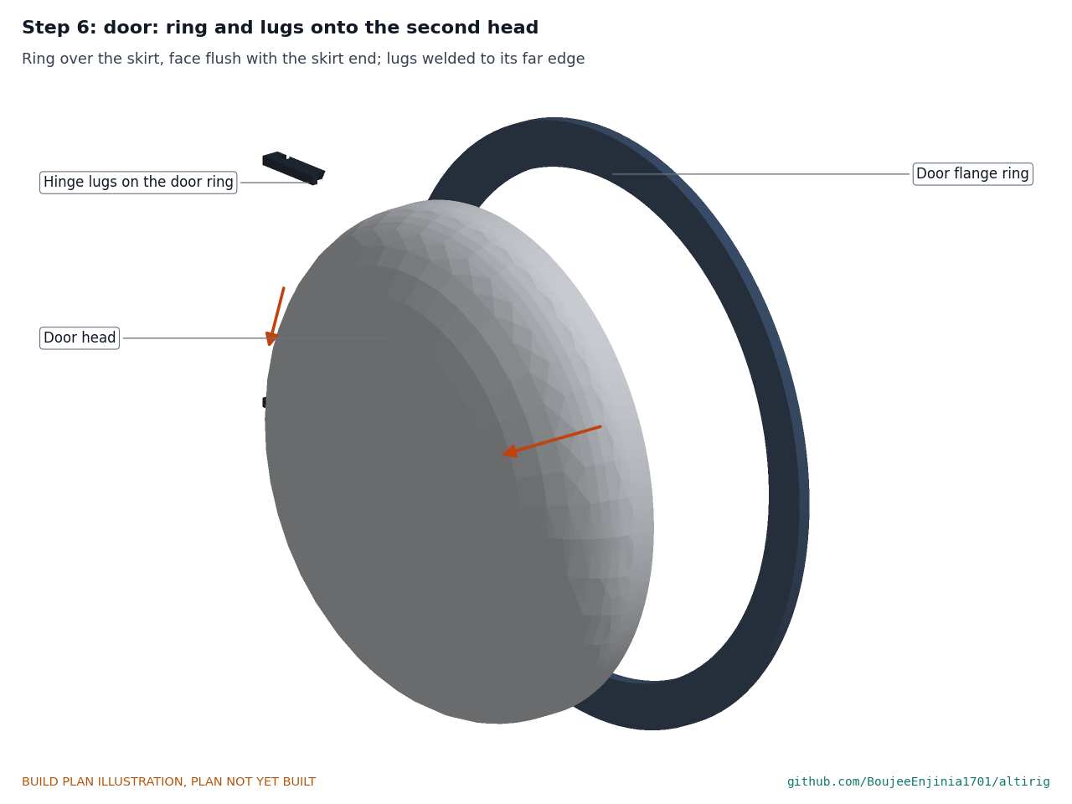
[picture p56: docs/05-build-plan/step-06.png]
Step 6


Weld the door ring onto the second head's skirt, face flush with the skirt end, and the two door lugs to its far edge.

### Step 7: hang the door

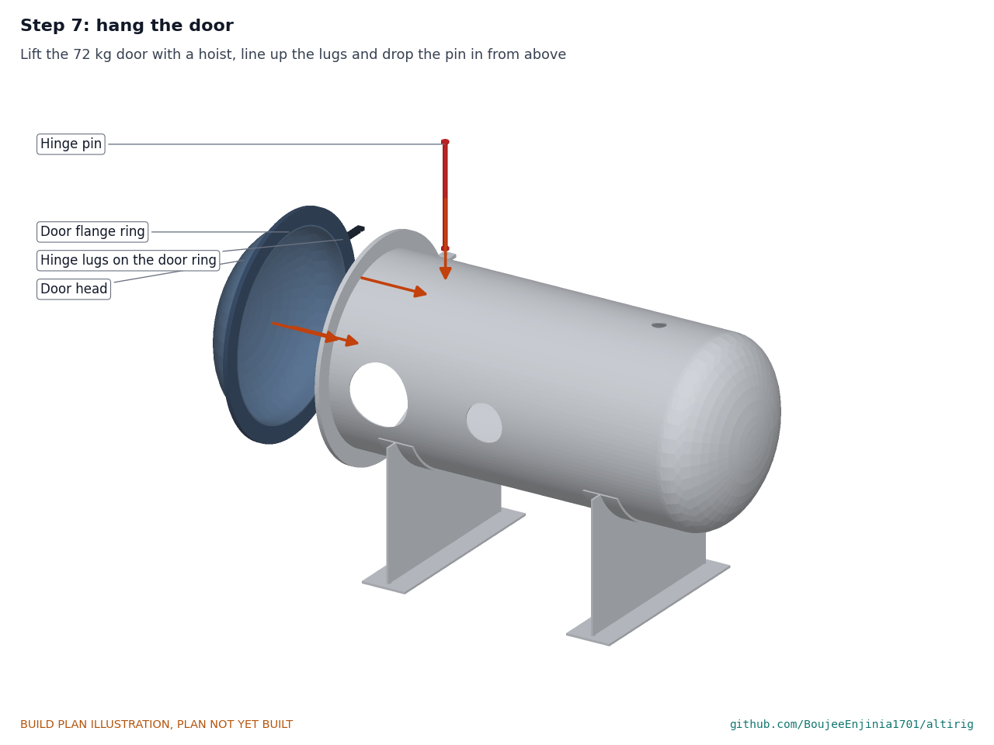
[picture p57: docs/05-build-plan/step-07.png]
Step 7


With the shell ring's lugs already welded, lift the 72 kg door with a hoist, line up its lugs just above the fixed lugs and drop the pin in from above. Fit the collar.

### Step 8: door gasket and latches

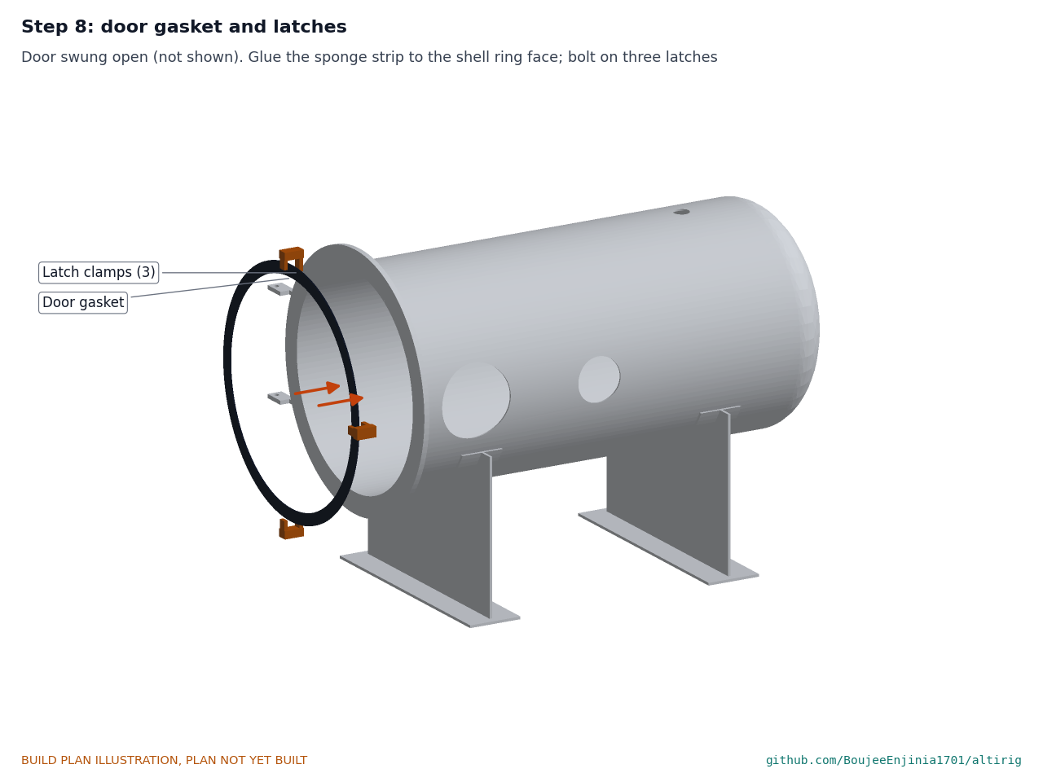
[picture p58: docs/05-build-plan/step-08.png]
Step 8


With the door swung open, glue the sponge strip to the shell ring's face with contact adhesive, joint at the bottom. Bolt the three latch clamps to the back of the shell ring. Fit the door interlock switch to the top latch.

### Step 9: window

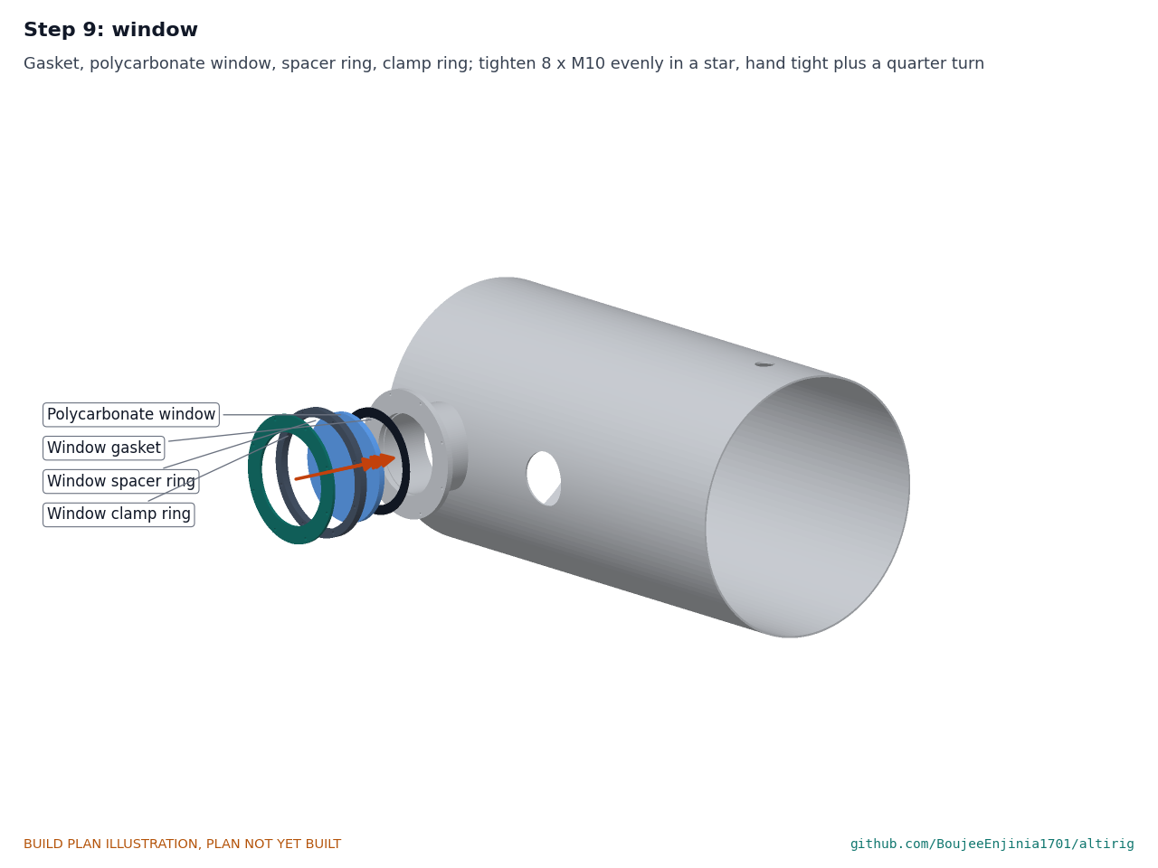
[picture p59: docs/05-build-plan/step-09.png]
Step 9


Lay the window gasket on the flange, then the window (film removed), the spacer ring and the clamp ring. Tighten the eight M10 bolts evenly in a star pattern, hand tight plus a quarter turn. Do not over-tighten: the spacer sets the squeeze.

### Step 10: feed-through plate

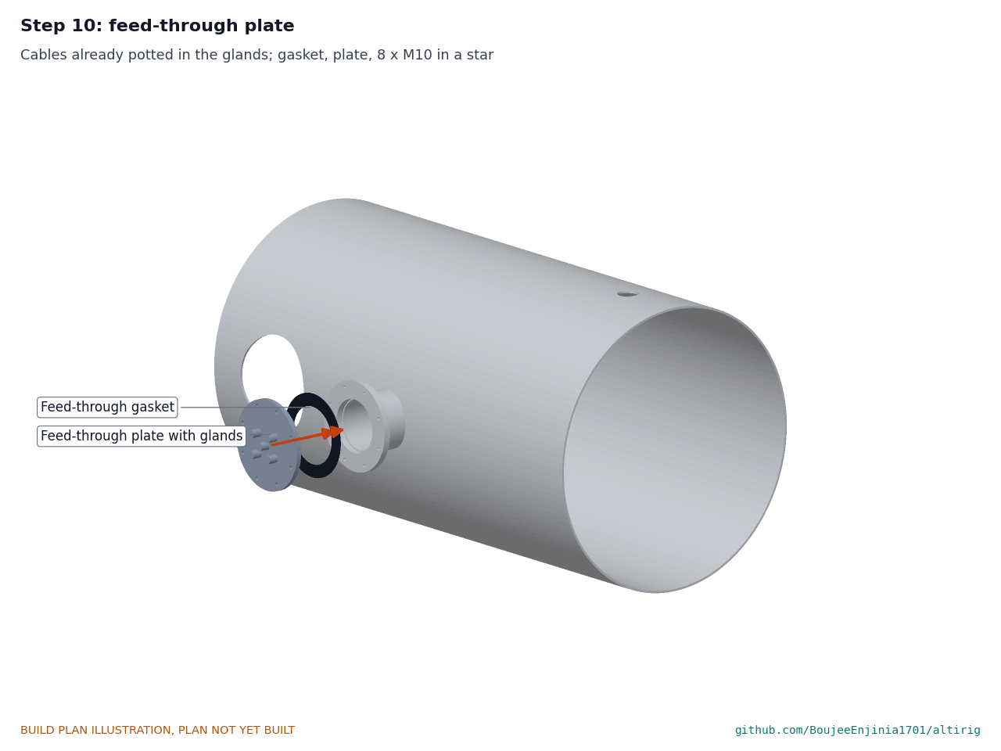
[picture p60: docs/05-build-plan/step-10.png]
Step 10


With the cables already potted in the glands, fit the gasket and the plate with eight M10 bolts in a star pattern.

### Step 11: valve manifold on the stub

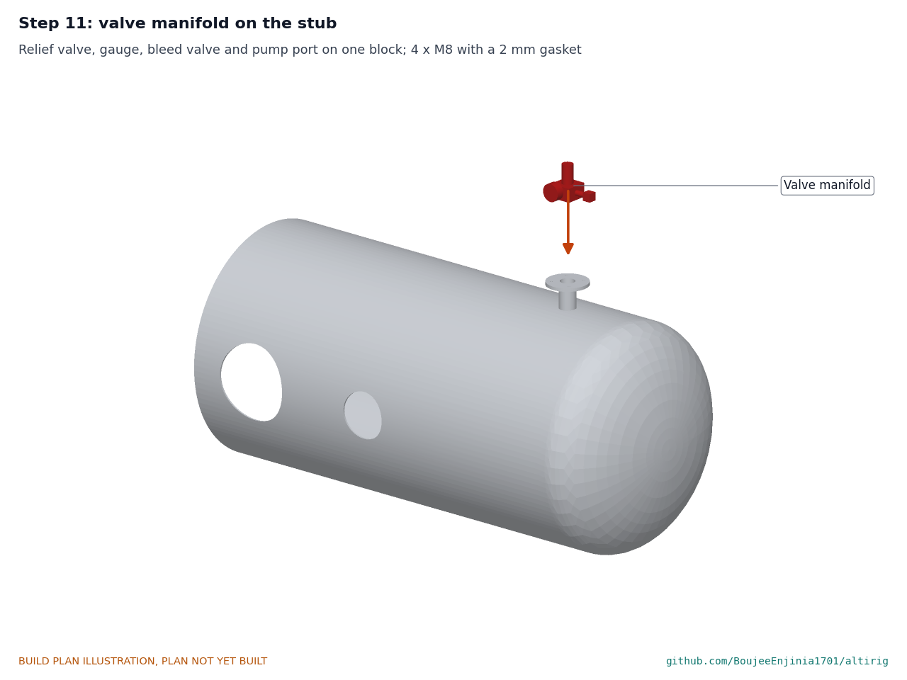
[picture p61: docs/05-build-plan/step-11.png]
Step 11


Bolt the assembled manifold to the stub flange with its gasket and four M8 screws, the gauge facing the window side.

### Step 12: baffle plate

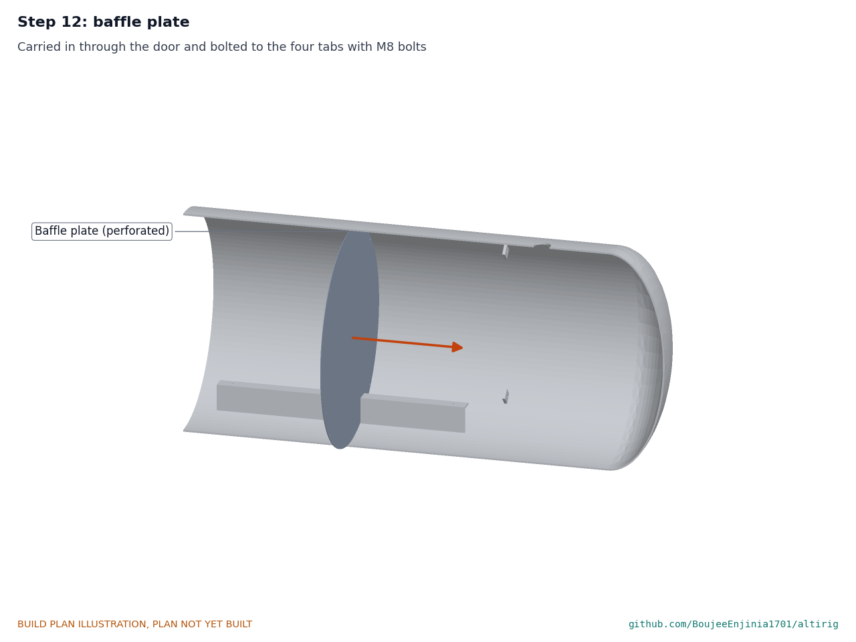
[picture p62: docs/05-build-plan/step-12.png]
Step 12


Carry the baffle in through the door, tilted, and bolt it to the four tabs.

### Step 13: deck plate

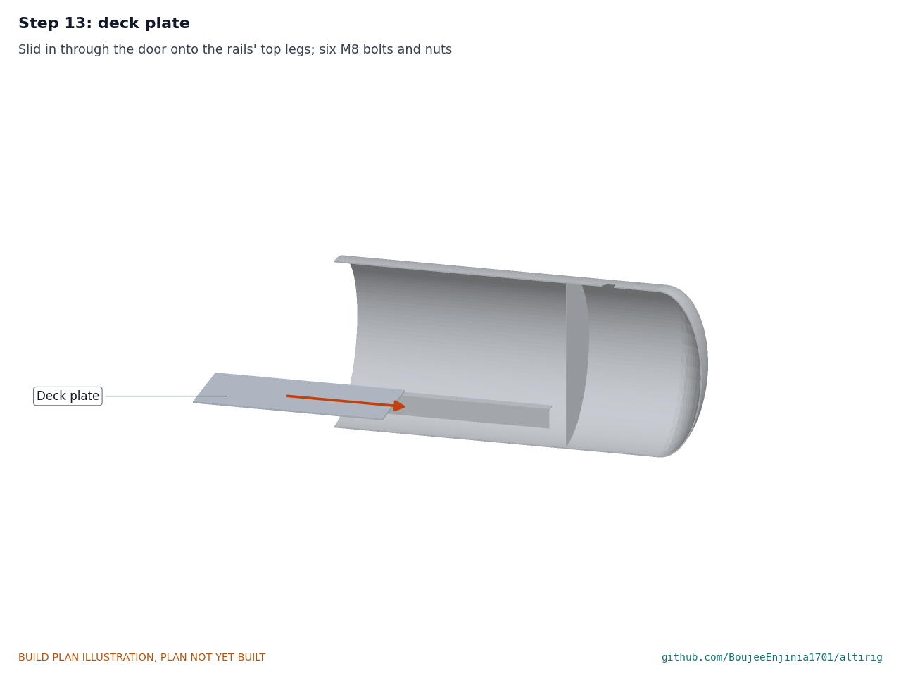
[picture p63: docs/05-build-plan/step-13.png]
Step 13


Slide the deck in through the door onto the rails and bolt it down with six M8 bolts and nuts.

### Step 14: stand base and flexures

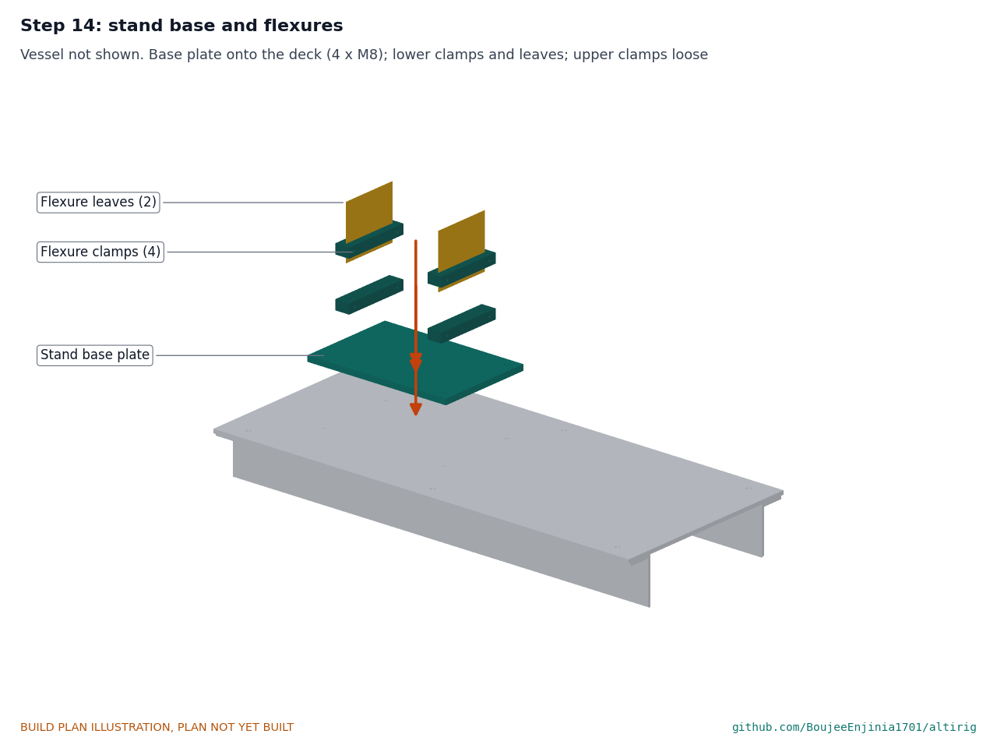
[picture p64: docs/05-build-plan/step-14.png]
Step 14


The vessel is not shown from here on. Screw the base plate to the deck. Screw the two lower clamps to it with the leaves gripped in them; fit the upper clamps on the leaves loosely.

### Step 15: thrust cell and carriage

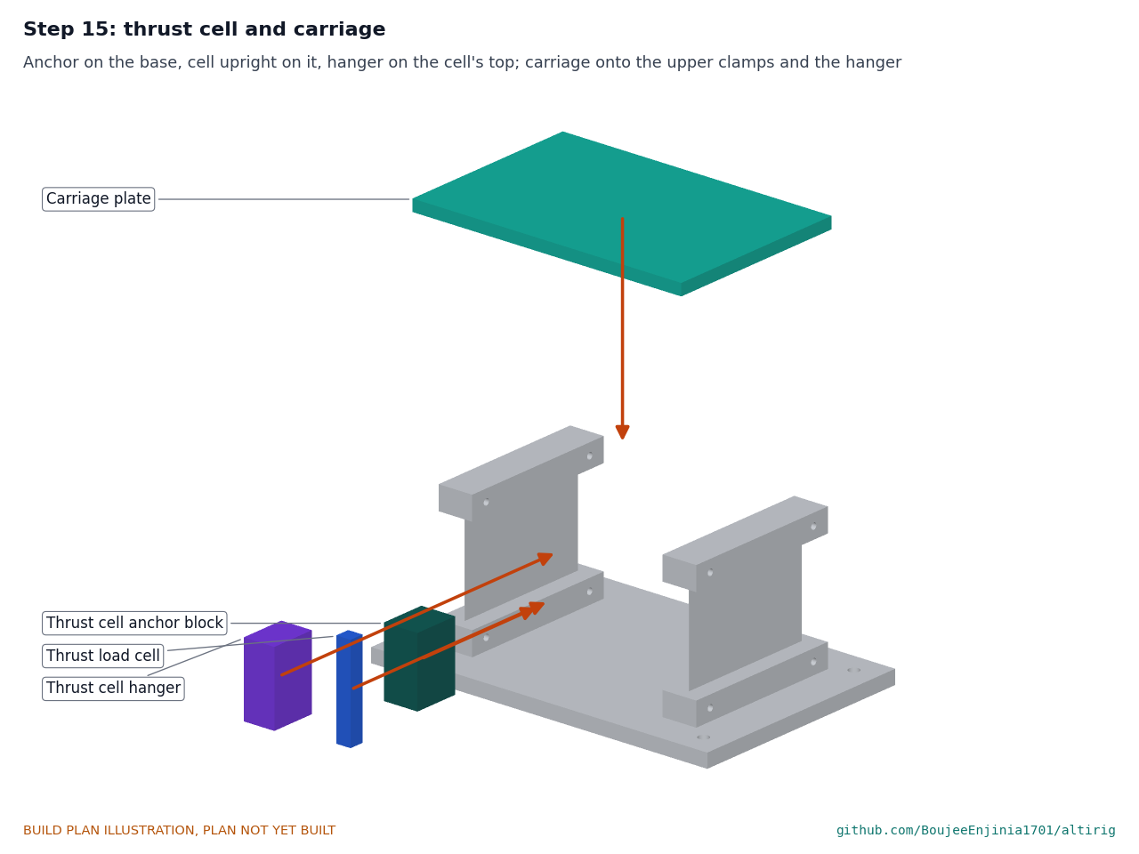
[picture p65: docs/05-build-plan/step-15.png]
Step 15


Screw the anchor block to the base, the thrust cell upright onto the anchor, and the hanger onto the top of the cell. Lower the carriage onto the upper clamps and the hanger and screw it down, with the 80 mm spacer between the clamps; then tighten all clamps and remove the spacer.

### Step 16: torque head

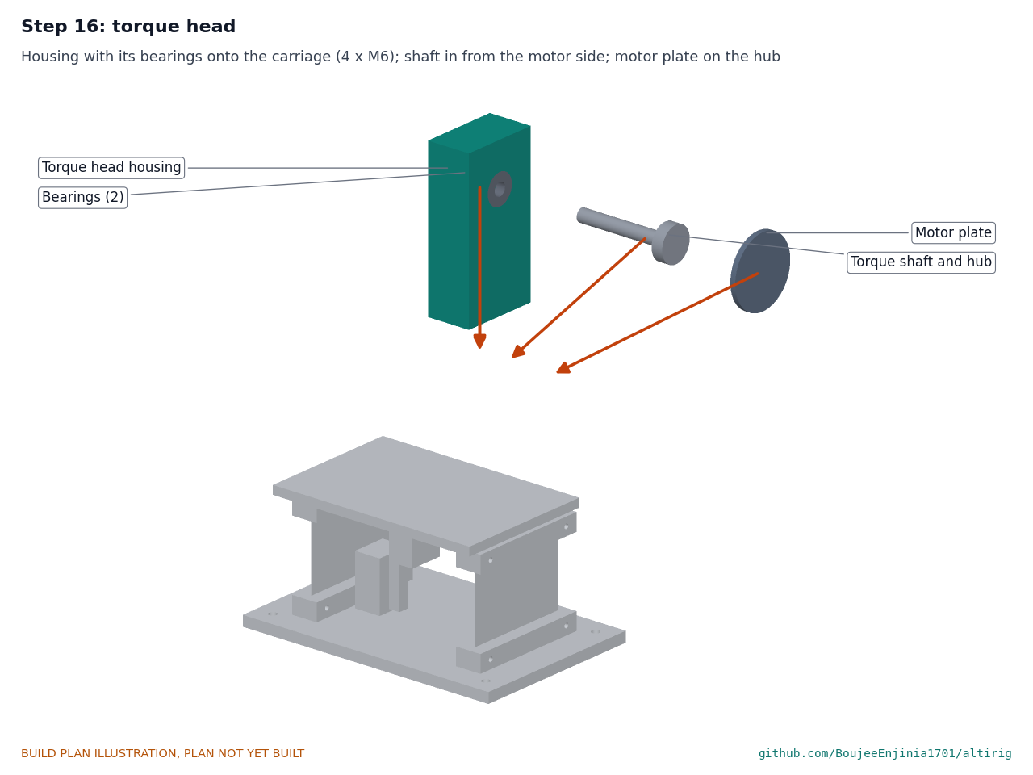
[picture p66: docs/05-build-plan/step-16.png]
Step 16


Screw the housing, with its bearings in, to the carriage with four M6 screws. Slide the shaft in from the motor side and screw the motor plate to its hub.

### Step 17: torque cell and arm

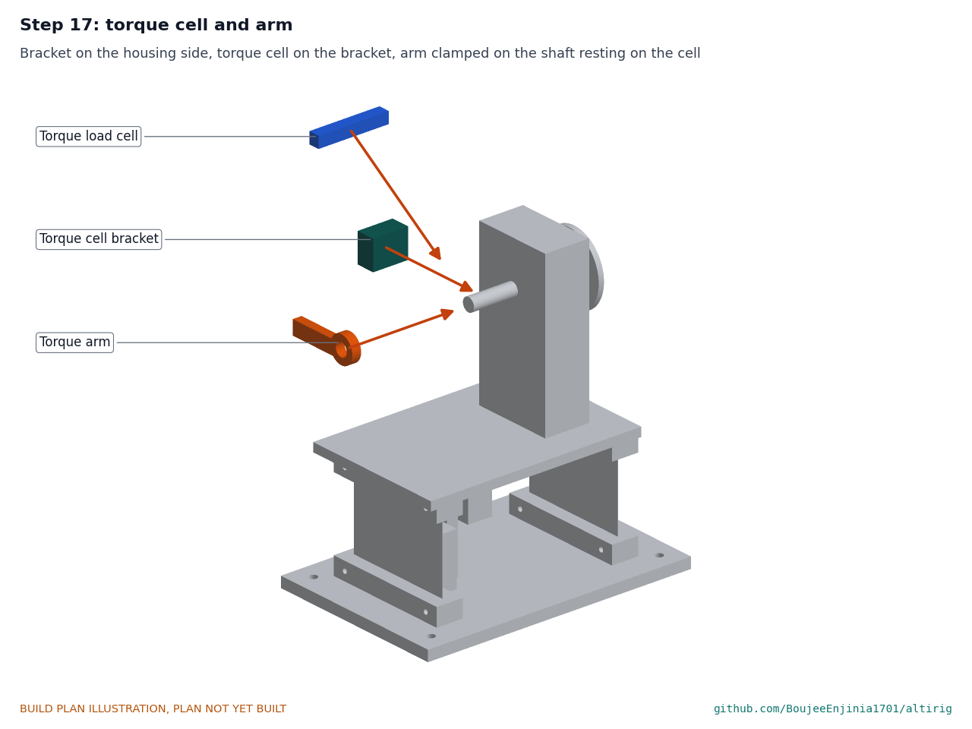
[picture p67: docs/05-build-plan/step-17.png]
Step 17


Screw the bracket to the housing's side and the torque cell onto the bracket. Clamp the arm on the shaft so its ball rests on the cell's free end.

### Step 18: speed sensor and air sensors

Step 18

Screw the speed post to the base plate. Place the air sensor box on the deck and run all cables along the deck to the feed-through, tied down so they cannot reach the propeller. Leave a loose loop in the motor and cell cables where they cross from the deck to the carriage.

### Step 19: motor and propeller under test

Step 19

Screw the motor to the motor plate with its own screws and thread-locker. Fit the propeller with the reflective tape on one blade. Connect the three motor phases at the feed-through.

### Step 20: pump, hose and control cabinet

Step 20

Stand the host lab's pump on the floor on the far side and lead its exhaust outdoors or to an extract. Connect the hose from the manifold to the pump. Stand the control cabinet in front of the door end on the window side, earth the vessel to the cabinet's earth bar, and wire the pump, bleed valve, sensors and interlocks. Set the host lab's DC supply beside the cabinet and feed it through the cabinet's motor contactor and emergency stop.

## 5. First checks

These are listed here and recorded in a TRL 4 test report; none has been done.

*Table 2. First checks.*

| Check | Requirement | How | Pass when |
| --- | --- | --- | --- |
| Door seats and latches | R11 | Close and latch; look for even gasket squeeze | Gasket squeezed evenly all round; interlock switch reads closed only when latched |
| Interlocks | R11 | Try to arm the motor with the door unlatched, without the key, and with the emergency stop pressed | The motor supply stays off in every case; the emergency stop also stops the pump and opens the bleed valve |
| Relief valve | R12 | Pump down with the motor off, watching the gauge | Relief valve opens at 55 kPa below atmosphere (46.3 kPa absolute), within 2 kPa |
| Proof pump-down | R7 | Behind the guard, pump to the relief setting and hold 10 min; inspect welds, window and door | No movement, cracking, crazing or noise; pressure rise under 0.3 kPa/min with the pump isolated |
| Pump-down time | R8 | Time from ambient to 54 kPa | 5 min or less |
| Density hold | R1, R2 | Hold 0.736 kg/m3 for 10 min with the motor off, then with it running | Within 1 % of set point |
| Thrust and torque calibration | R3, R4 | Masses over the pulley along the axis; masses on the calibration arm | Errors within 1 % of 50 N and 2 % of 2 N m, before and after a test series |
| Speed | R4 | Optical sensor against a handheld tachometer | Within 0.5 % |
| Fit of the largest propeller | R5 | Turn a 380 mm propeller by hand | Clears the wall, the deck and the speed sensor |
| Chamber effect | R6 | Same propeller at the same speeds at ambient pressure in the chamber and on an open-air stand, with and without the baffle | Within 5 % (see the design decisions register) |
| Data | R9 | Inspect a logged file | CSV with density, thrust, torque, speed, voltage and current at 10 Hz or more |

## 6. Safety stops

Work stops at each point below until everything listed is true.

1. **Before the first pump-down.** A qualified engineer has reviewed the vessel calculation (ALR-CAL-001, section B) and the welds; the rear head and both flange rings are welded continuously all round; the window is polycarbonate; the relief valve has been set on a separate test and is fitted.
2. **Before every pump-down.** The guard is in place in front of the window; nobody stands in line with the window or the door; the door is latched and the gasket is clean; the gauge reads zero; the pump exhaust is led away.
3. **Before arming the motor.** The propeller is tight and undamaged; no tools, cables or loose parts are inside; the door is latched and the interlock reads closed; the arming key is turned by the operator, who keeps it; everyone is outside the line of the propeller plane. The motor is only run with the chamber closed.
4. **Before opening the door.** The motor is disarmed and stopped; the chamber is vented through the bleed or vent valve until the gauge reads zero. Never force the door: under vacuum it is held by tonnes of force.
5. **Batteries.** No battery pack goes inside the chamber.
6. **After any overpressure, crack, crazing or impact.** Stop, vent, and do not pump down again until the part is inspected and replaced if needed.

## 7. Tools, skills and workspace

- **Welding shop:** a qualified welder for the vessel welds (full-penetration butt weld of the rear head, fillet welds on rings, nozzles, saddles, rails, tabs and lugs); plasma or waterjet cutting of plate; a plate roll for the wear plates; a hoist for the shell and the door.
- **Machine shop:** a lathe for the shaft and a mill or boring head for the housing bore; drilling and tapping to M10.
- **Lab:** a level floor with room for the 2 m vessel and the door to swing open, a mains supply with an RCD, an extract or outdoor vent for the pump exhaust, hearing protection and safety glasses, a guard (for example a 6 mm polycarbonate sheet on a frame) for proof tests.
- **Skills:** basic electrical wiring of a control cabinet by a competent person; load cell wiring and calibration.

## 8. Where the numbers come from

- `cad/src/model.py`: the parametric model and every dimension (STEP in `cad/step/`).
- `cad/drawings/ALR-DWG-001`: general arrangement; `cad/drawings/ALR-DWG-101` to `ALR-DWG-122`: making sketches.
- `cad/src/build_plan_media.py`: the pictures in this plan.
- `docs/04-calcs/01-sizing.md` and `docs/04-calcs/sizing.py` (ALR-CAL-001): strength, pump-down, density, stand and chamber effect.
- `bom/bom.csv`: parts, specifications and prices.
- `docs/decisions/0002-design-for-construction.md` (ALR-DDR-002): the changes made for construction.

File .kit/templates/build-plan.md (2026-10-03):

---
doc_id: PRJ-BLD-001
title: Project prototype build plan
project: Project name
doc_type: Build plan
version: "0.1"
status: Draft
date: YYYY-MM-DD
author: Amish Chadha
license: CERN-OHL-S-2.0
revisions:
  - version: "0.1"
    date: YYYY-MM-DD
    author: Amish Chadha
    change: First build plan; design made constructable
---

# Project prototype build plan

**Plan, not yet built.** How to build the first proof-of-concept prototype, component by component. Building and testing to it is TRL 4 work. Decisions still to be made are kept in the design decisions register (`docs/06-design-decisions.md`), not here.

## 1. What you are building

Every component, pulled apart and numbered in build order

One short paragraph: what the prototype is, how many components, which are made and which are bought, and the main ways they are made.

## 2. What changed to make it buildable

| Component | The concept had | The buildable design has | Why |
| --- | --- | --- | --- |

## 3. Making the components

### 3.1 Component name

Making sketch

**What it is and what it is made from.**

**How to make it.**

1. Mark out ...
2. Cut ...

**How it fits the parts next to it.**

Close-up of the joint

**Check before moving on.**

## 4. Putting it together

### Step 1: ...

Step 1

## 5. First checks

| Check | Requirement | How | Pass when |
| --- | --- | --- | --- |

## 6. Safety stops

## 7. Tools, skills and workspace

## 8. Where the numbers come from

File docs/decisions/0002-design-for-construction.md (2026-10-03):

---
doc_id: ALR-DDR-002
title: AltiRig design for construction
project: AltiRig
doc_type: Design decision record
version: "0.1"
status: Draft
date: '2026-10-03'
author: Amish Chadha
license: CERN-OHL-S-2.0
revisions:
- version: "0.1"
  date: '2026-10-03'
  author: Amish Chadha
  change: Constructability review and changes C1 to C17, decided under Amish's 2026-10-03 pre-approvals
---

# 0002: Design for construction

- **Date:** 2026-10-03
- **Status:** decided. Amish, 2026-10-03: "start with the first 14 repos from the list of 29 projects. I pre-approve the batch runs along with any recommendations you come up with. I also accept any cost overruns or variations from the assumed scope cost." And, for this batch: "Proceed with the remaining 15 scaffolds". Standard section 18 (Amish, 2026-09-30): "fix the design assumptions to match and be physically feasible".

## Context

The TRL 2 concept named a vessel, a window, feed-throughs, a stand and baffles but not how any of them is made or held. The constructability review went through every component: how it is made, which faces touch its neighbours, what holds them, and in what order it goes together. The model (`cad/src/model.py`) was checked with build123d for overlaps between every pair of parts (none remain) and for clearances (`clearances()`); the masses come from the solids. Nothing below changes what AltiRig does, its pitch or its safety case; the safety-related changes (C3, C15, C16) are all in the conservative direction.

> **Safety:** The vessel is a vacuum vessel. Welding on it is done by a qualified welder, and no part of it is put under vacuum until the safety stops in ALR-BLD-001, section 6, are passed.

## Changes

*Table 1. Changes made for construction.*

| # | Component | The concept had | The constructable design has | Why |
| --- | --- | --- | --- | --- |
| C1 | Shell | "A steel drum or tank" | An 813 x 6.35 mm pipe offcut, 1,500 mm long, ends square, holes cut to the nozzle outside sizes | A stocked item; round within 1 % so the buckling calculation holds |
| C2 | Flange rings and door seal | A door with no detail | Two 20 mm plate rings, 960 OD, bored to fit over the pipe and over the door head's skirt; fillet welded both sides; a 6 mm closed-cell EPDM sponge gasket glued to the shell ring's face | Flat cut rings need no machining; the sponge takes up 1 to 2 mm of weld distortion; under vacuum the air closes the joint |
| C3 | Nozzles | A window and feed-throughs in the wall | Heavy-wall set-in stubs (10 in XS for the window, 6 in XS for the feed-through) with square-cut ends standing 16 to 40 mm into the vessel, welded inside and out; no reinforcing pads | No saddle-shaped contour cut on the stub; the heavy wall replaces the metal removed (1.7 and 2.3 times the area needed) |
| C4 | Window | "A polycarbonate or laminated window" | A 340 mm, 20 mm polycarbonate disc on a 6 mm EPDM ring gasket, held by a 10 mm clamp ring over a 25 mm spacer ring with 8 x M10 into the tapped flange | The spacer sets the gasket squeeze (6 to 5 mm) so the window is never over-clamped; no holes in the window |
| C5 | Feed-through | "Sealed feed-through connectors" | A 15 mm aluminium plate with five M20 IP68 glands, cables potted in epoxy for 50 mm, on a 2 mm gasket | Stock glands; potting stops air leaking along the strands |
| C6 | Saddles | Not shown | Two welded saddles: 10 mm web with a curved top, rolled wear plate over 120°, base plate with two anchor holes | Carries the 470 kg vessel at axis height 800 mm with the load spread along the wear plates |
| C7 | Deck | Not shown | Two 50 x 50 x 6 angles welded inside, hanging legs scribed to the wall; an 8 mm aluminium deck bolted to the top legs | The stand needs a flat, removable base; the deck slides in through the door |
| C8 | Baffle | "Flow straightener and baffles" | One 790 mm perforated steel disc, 63 % open, bolted to four welded tabs 590 mm downstream of the propeller | Removable, so the comparison runs can be made with and without it (R6) |
| C9 | Hinge | Not shown | Two 15 mm lugs on each flange ring and a 20 mm pin on the far side; the door lugs' holes slotted 3 mm | Carries the 72 kg door; the slot lets the door seat evenly on the gasket |
| C10 | Latches | Not shown | Three bolt-on latch clamps, at least 3 kN each, at the top, the window side and the bottom | Pull the door into the sponge for the first seal (6.3 kN in all); vacuum does the rest |
| C11 | Thrust stand | "Load cells measuring thrust" | 12 mm base plate; two 0.5 mm spring-steel leaves in slit aluminium clamps; anchor block and hanger holding an upright 10 kg bar cell; 10 mm carriage | A bending-beam cell must be loaded across its length: standing it upright lets the carriage push its top end along the axis |
| C12 | Torque head | "Reaction torque" | Housing bored for two 6202 bearings; 15 mm shaft with a hub and an 80 mm motor plate; a 60 mm arm clamped on the shaft resting on a 5 kg cell on a bracket, through a 3 mm ball | The motor's reaction torque is read without the thrust passing through the torque cell; bearing friction 0.001 N m |
| C13 | Speed sensor | "Optical or electrical RPM" | Optical sensor on an aluminium post on the base plate, 15 mm from the propeller plane, 140 mm below the axis | Fixed to the stand so it moves with nothing; clear of the blades |
| C14 | Valve manifold | "Bleed valve" | A 2 in stub with a tapped 150 mm flange on top; a bought manifold of fittings (relief valve, gauge, bleed and needle valve, vent valve, isolation valve, pump port) bolted on with a gasket | Every valve is a stock fitting; one flange to seal |
| C15 | Bleed valve | Any bleed valve | A normally-open solenoid bleed valve | The chamber vents if power is lost or the emergency stop is pressed (R11) |
| C16 | Feed-through position | Not placed | On the window side, 740 mm from the flange face, 20.9° clear of the propeller plane | Keeps the cable plate out of the fragment zone and close to the control cabinet |
| C17 | Pump and cabinet | Not placed | Pump on the floor on the far side with its exhaust led outdoors; cabinet in front of the door on the window side, so the operator sees the window and reaches the emergency stop | The door swings to the far side; the operator's side stays clear |

## Consequences

- The general arrangement is at Rev P2 (ALR-DWG-001); making sketches ALR-DWG-101 to 122 and the build plan ALR-BLD-001 describe this design.
- The calculations were re-run (ALR-CAL-001 v0.2). The set-in nozzles meet the opening area rule without pads; the stand error budgets are unchanged.
- The bill of materials gains the gaskets, latches, spacer and clamp rings, tabs, hinge and welding labour; the estimated cost is USD 4,920 against the USD 1,000 value-engineering target.
- `design_state: constructable` is set in `project.yaml`.

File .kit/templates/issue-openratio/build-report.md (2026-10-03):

---
name: Build report
about: Tell us what happened when you built, printed or tested part of this design
title: "Build report: "
labels: build-report
---

This is a research and educational prototype, not a medical device. It is a TRL 3 concept and is not released for fabrication. If you build any part of it, you do so at your own risk. Reports help everyone.

**What you built** (part, sub-assembly or test)

**Materials, tools and settings**

**What worked**

**What did not work, with photos or measurements if you have them**

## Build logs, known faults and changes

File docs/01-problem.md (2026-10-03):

---
doc_id: ALR-PRB-001
title: AltiRig problem statement
project: AltiRig
doc_type: Problem statement
version: "0.2"
status: Draft
date: '2026-10-03'
author: Amish Chadha
license: CERN-OHL-S-2.0
revisions:
- version: "0.1"
  date: '2026-09-30'
  author: Amish Chadha
  change: Initial scaffold
- version: "0.2"
  date: '2026-10-03'
  author: Amish Chadha
  change: TRL 2 review; open questions settled under Amish's 2026-10-03 pre-approval (ALR-DDR-001); co-design candidate named; density target at room temperature clarified
---

# AltiRig problem statement

Thrust and power depend on air density. Most drone makers test propellers and motors in their own workshop air, then learn how they behave at altitude only when they fly there.

## The problem

The thrust and power coefficients that describe a propeller both include air density ([Tyto Robotics](https://www.tytorobotics.com/blogs/articles/how-to-measure-propeller-performance-coefficients)). At the same speed, a propeller at 5,000 m, where density is about 60% of sea level ([Engineering ToolBox](https://www.engineeringtoolbox.com/standard-atmosphere-d_604.html)), makes much less thrust, so the motor must spin faster, draw more current and run hotter to hold a hover. Small propellers also run at low Reynolds numbers, where published performance data show strong effects of size and speed ([Brandt and Selig, UIUC, 2011](https://m-selig.ae.illinois.edu/pubs/BrandtSelig-2011-AIAA-2011-1255-LRN-Propellers.pdf)); thinner air pushes them further into that range, so sea-level data cannot simply be scaled.

Tools exist but not in the right form. Thrust stands such as the Tyto Robotics Flight Stand 50 measure up to 50 kgf of thrust, torque and power, but at room conditions ([Tyto Robotics](https://www.tytorobotics.com/pages/flight-stand-50)). Research groups have tested small unmanned aircraft in low-pressure, low-temperature facilities ([Politecnico di Torino, UAS testing in low pressure and temperature conditions](https://www.researchgate.net/publication/347154436_UAS_testing_in_low_pressure_and_temperature_conditions)), and industrial altitude chambers are sold for equipment testing ([Sanatron](https://www.sanatron.com/articles/altitude-test-chamber-how-vacuum-chambers-simulate-high-altitudes.php)). What is missing is an open, low-cost chamber with a built-in thrust stand that a small team can build and use to choose propellers for a specific altitude.

## Users and context

| User | Need | Context |
| --- | --- | --- |
| Kitewright frame and payload builders | Measured thrust and power at 5,000 m density for Lift and Range propulsion | Design and verification before high-altitude flights |
| University aerospace and mechanical labs | An affordable way to study propellers in thin air | Teaching and research labs near sea level |
| Mountain rescue and survey drone operators | Confidence that a drone has hover margin at the altitude of a job | Pre-season checks of aircraft and spare propellers |
| Independent drone makers | Published, comparable altitude data for common propellers and motors | Choosing parts for high-altitude builds |

## Operating environment

- Indoor workshop or lab at or near sea level, on a solid bench or floor.
- Chamber interior from ambient pressure down to about 54 kPa (7.8 psi), the pressure at 5,000 m ([Engineering ToolBox](https://www.engineeringtoolbox.com/standard-atmosphere-d_604.html)); extension to 47 kPa (6,000 m) as a stretch target. Because the chamber air is at room temperature, not at the -17.5 °C of 5,000 m, the density of 5,000 m is reached at a higher pressure: about 61.9 kPa at 20 °C (ALR-CAL-001, section A). AltiRig matches density, which sets thrust and power, and records pressure and temperature with every run.
- Room temperature in the base version; optional chilling towards -20 C is a later variant.
- Mains power for the vacuum pump and a bench power supply or battery for the motor under test.

## Constraints

- Prototype budget ceiling USD 1,000 for chamber, pump, stand and instruments.
- Propellers up to about 380 mm (15 in) diameter in the first version (target).
- Pressure vessel designed with a clear safety factor against collapse; the pressure difference at 5,000 m equivalent is about 47 kPa (6.8 psi), which loads a large flat panel heavily.
- Built from bought parts and simple fabrication; no machining beyond a maker-space level.
- Open design: hardware under CERN-OHL-S-2.0, logging software under an open software licence.

## Out of scope

- Forward-flight (wind tunnel) testing; AltiRig covers static and hover thrust only.
- Full environmental certification testing to aerospace standards.
- Testing of combustion engines or fuel systems.
- Rating any propeller or motor as certified for flight; results are engineering data only.

## Prior work

| Prior work | What it does | Gap for these users | Source |
| --- | --- | --- | --- |
| Tyto Robotics Flight Stand 50 | Commercial thrust stand measuring up to 50 kgf thrust, 30 Nm torque, speed and electrical and mechanical power | Measures at room conditions only; no altitude simulation | [link](https://www.tytorobotics.com/pages/flight-stand-50) |
| UAS testing in low pressure and temperature conditions (Politecnico di Torino) | Research on testing small unmanned aircraft in a low-pressure, low-temperature facility | Institutional facility; not an open, buildable design | [link](https://www.researchgate.net/publication/347154436_UAS_testing_in_low_pressure_and_temperature_conditions) |
| Industrial altitude test chambers | Vacuum chambers that simulate high altitude for equipment testing | Built for general equipment; no integrated propeller thrust stand; industrial cost | [link](https://www.sanatron.com/articles/altitude-test-chamber-how-vacuum-chambers-simulate-high-altitudes.php) |
| UIUC propeller performance data (Brandt and Selig, 2011) | Measured performance of small propellers at low Reynolds numbers | Measured at test-section density; does not show performance at 5,000 m directly | [link](https://m-selig.ae.illinois.edu/pubs/BrandtSelig-2011-AIAA-2011-1255-LRN-Propellers.pdf) |

## Co-design

A university aerospace or mechanical engineering lab with a thrust stand or vacuum equipment, because they can check chamber safety, calibrate the stand and compare results with their own data. The first candidate to approach is the Department of Aerospace Engineering at IIT Kanpur, which has propeller and wind tunnel facilities and works with Himalayan users; the second is the Department of Mechanical Engineering at Kathmandu University, close to the Nepal users. Both are candidates, not agreed partners (ALR-DDR-001, D11).

Co-design checklist:

- [ ] Partner reviews the vessel calculation (ALR-CAL-001, section B) before any pump-down.
- [ ] Partner witnesses the first proof pump-down behind the guard.
- [ ] Side-by-side runs of the same propeller on the partner's open-air stand and in AltiRig at ambient pressure (R6).
- [ ] Partner agrees which propellers are tested first and how data are published.

## Open questions settled at the TRL 2 review

These were settled on 2026-10-03 under Amish's pre-approval; each is argued in ALR-DDR-001.

- **Closed-chamber accuracy.** A closed chamber is used, with a vessel 2.1 times the largest propeller diameter, a removable perforated baffle and side-by-side comparison runs at ambient pressure (R6). Whether R6 is met is still to be shown; the estimate and the options are in ALR-CAL-001, section F, and in the review note.
- **Cold air.** The first version runs at room temperature and matches density, not temperature. Chilling towards -20 °C is a later variant.
- **Vessel type.** A horizontal steel vessel made from an 813 mm (32 in) pipe offcut with two bought 2:1 ellipsoidal tank heads, one as the door. A thin steel drum would collapse under vacuum and a flat-panelled box needs heavy ribs, so both were rejected.
- **Propeller, motor and tuning kit.** It is not part of this repo. AltiRig publishes measured data; the Kitewright Lift and Range frames publish their propulsion kits using that data.

## Safety

> **Safety:** AltiRig is a vacuum vessel with a spinning propeller inside. At the 5,000 m density point the air outside pushes on the vessel with about 39 kPa, and the door alone carries about 24 kN (2.5 t). A collapsed vessel or a failed window can throw fragments; a propeller that breaks at speed releases fragments in its own plane. The motor supply and the vacuum pump run from mains power. AltiRig is an open engineering reference, not certified pressure or test equipment.

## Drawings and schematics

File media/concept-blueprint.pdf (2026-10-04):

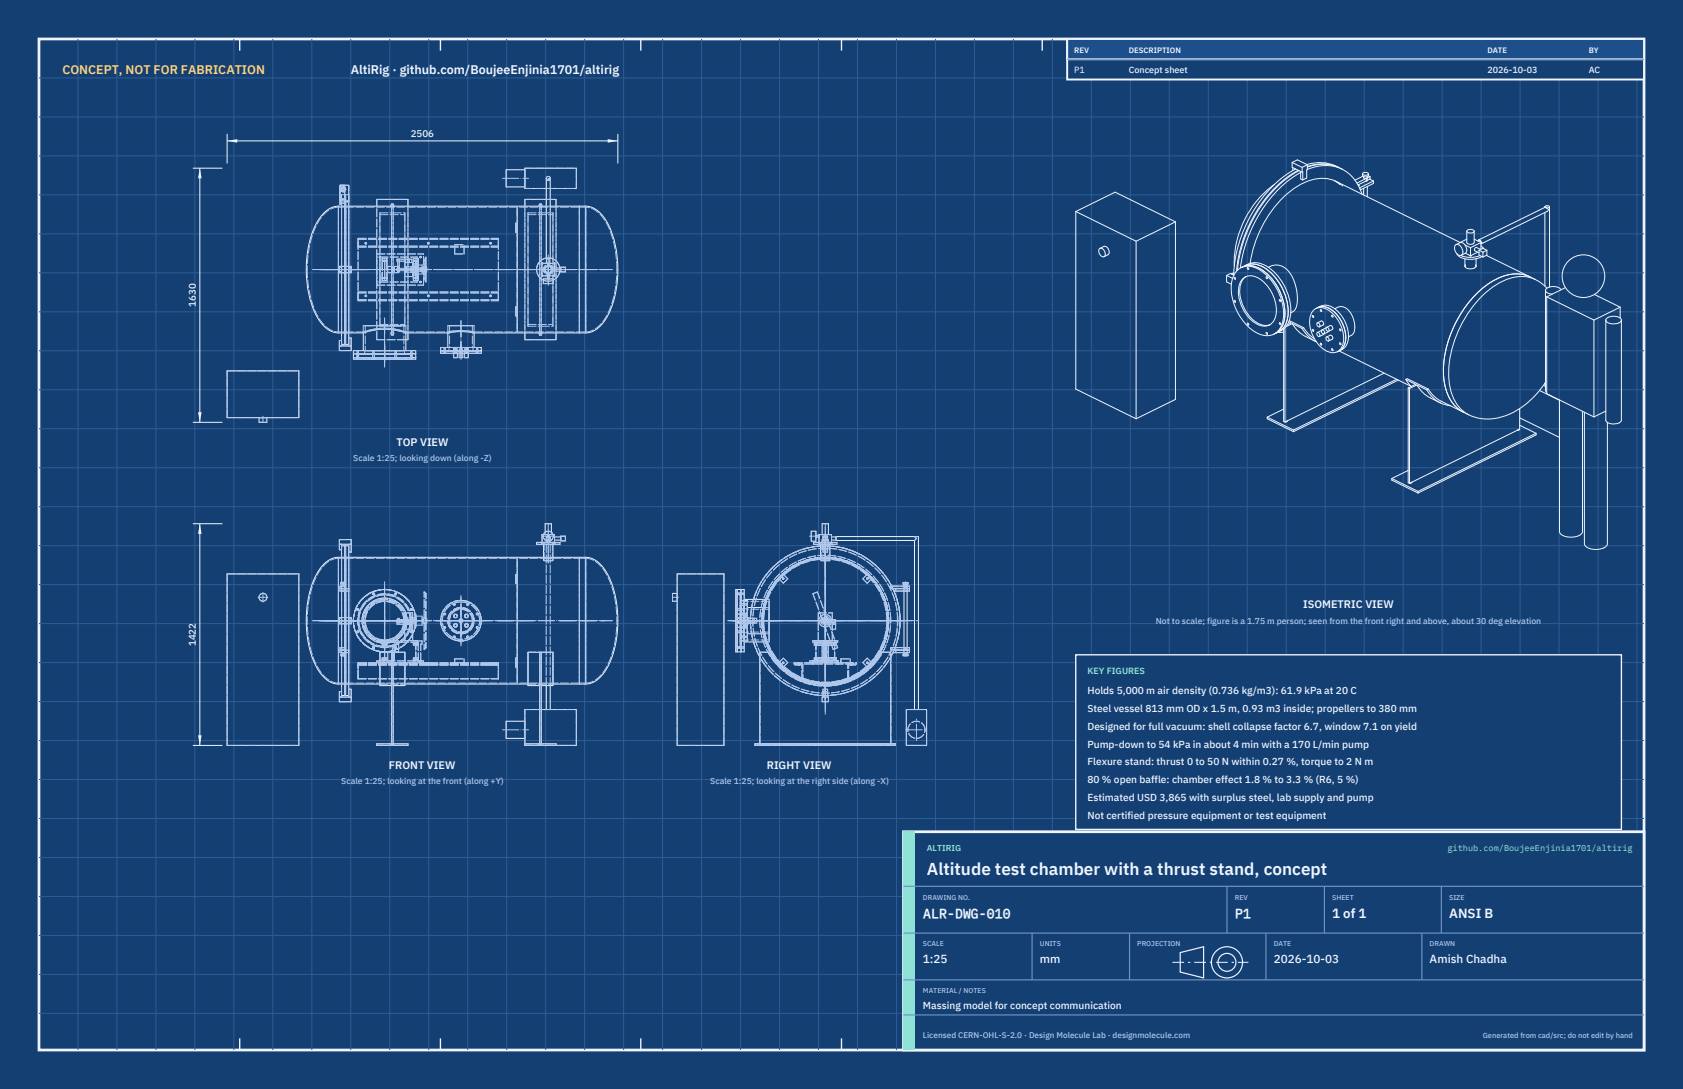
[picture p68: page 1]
CONCEPT, NOT FOR FABRICATION; AltiRig · github.com/BoujeeEnjinia1701/altirig; FRONT VIEW; TOP VIEW; RIGHT VIEW; ISOMETRIC VIEW; REV; DESCRIPTION; DATE; Concept sheet; ALTIRIG; github.com/BoujeeEnjinia1701/altirig; DRAWING NO. ALR-DWG-010; REV P1; SHEET 1 of 1; SIZE ANSI B; SCALE 1:25; UNITS mm; PROJECTION; DRAWN Amish Chadha; Licensed CERN-OHL-S-2.0 · Design Molecule Lab · designmolecule.com; Generated from cad/src; do not edit by hand

Scale 1:25; looking down (along -Z)

Not to scale; figure is a 1.75 m person; seen from the front right and above, about 30 deg elevation

KEY FIGURES
Holds 5,000 m air density (0.736 kg/m3): 61.9 kPa at 20 C
Steel vessel 813 mm OD x 1.5 m, 0.93 m3 inside; propellers to 380 mm
Designed for full vacuum: shell collapse factor 6.7, window 7.1 on yield
Pump-down to 54 kPa in about 4 min with a 170 L/min pump
Flexure stand: thrust 0 to 50 N within 0.27 %, torque to 2 N m
80 % open baffle: chamber effect 1.8 % to 3.3 % (R6, 5 %)
Estimated USD 3,865 with surplus steel, lab supply and pump
Not certified pressure equipment or test equipment

Scale 1:25; looking at the front (along +Y)

Scale 1:25; looking at the right side (along -X)

Altitude test chamber with a thrust stand, concept

MATERIAL / NOTES
Massing model for concept communication

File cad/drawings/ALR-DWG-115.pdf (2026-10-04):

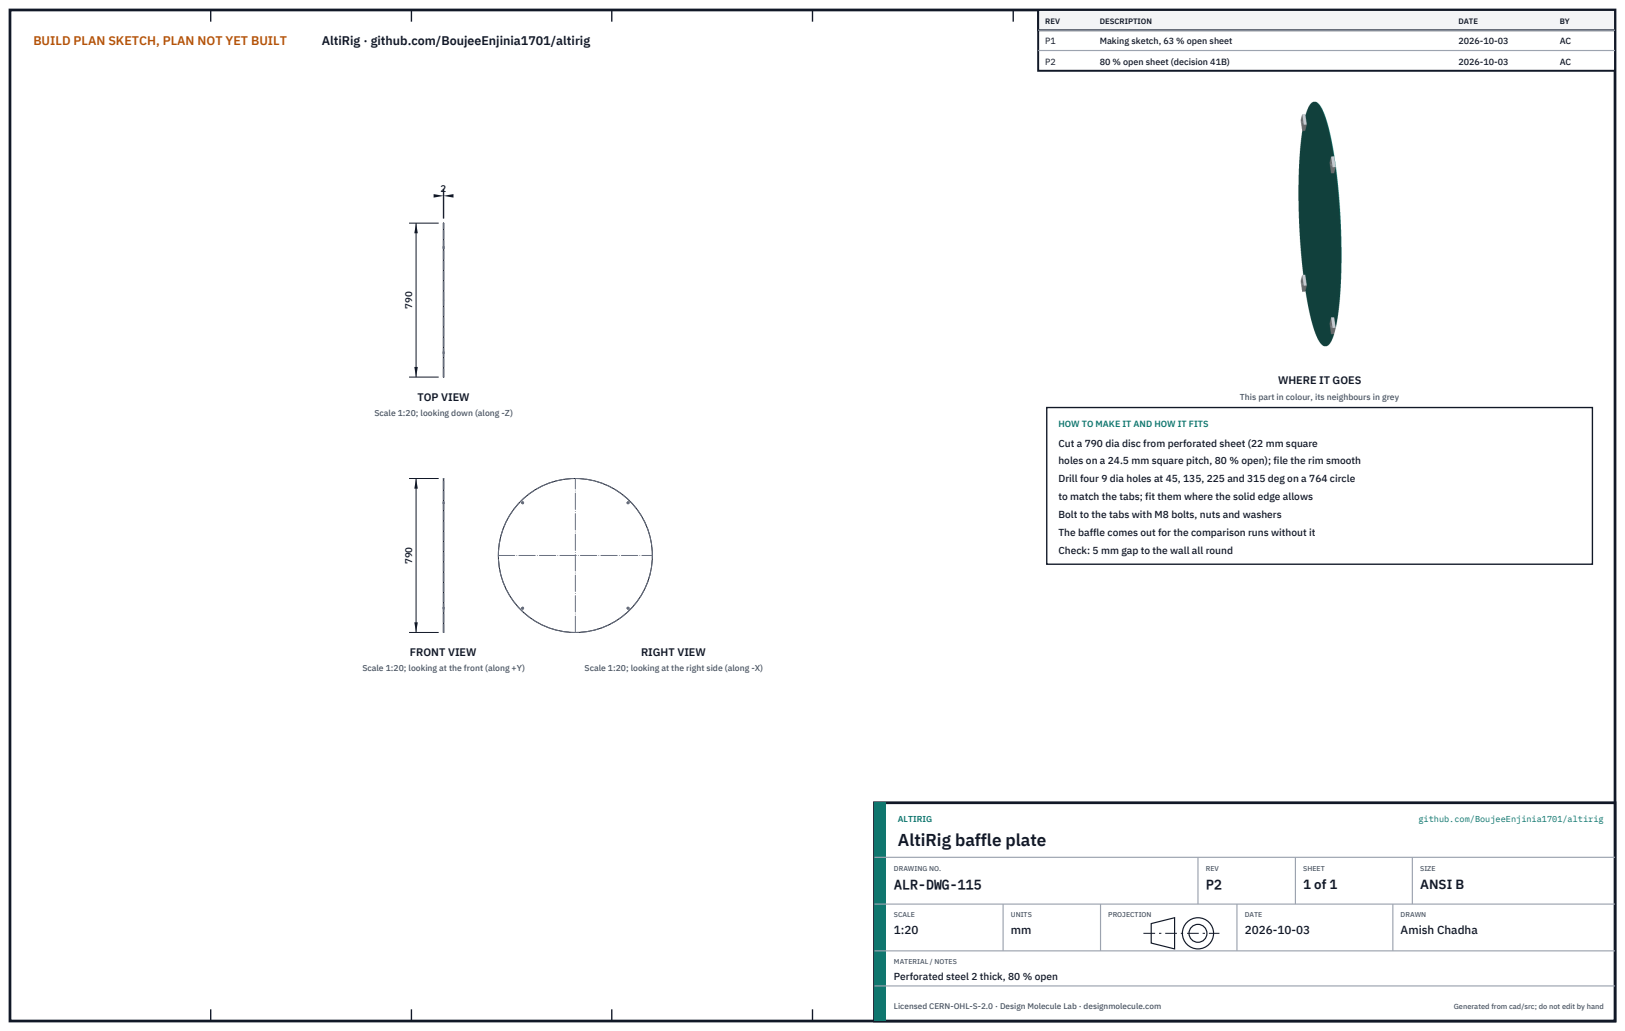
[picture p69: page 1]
BUILD PLAN SKETCH, PLAN NOT YET BUILT; AltiRig · github.com/BoujeeEnjinia1701/altirig; FRONT VIEW; TOP VIEW; RIGHT VIEW; REV; DESCRIPTION; DATE; Making sketch, 63 % open sheet; 80 % open sheet (decision 41B); ALTIRIG; github.com/BoujeeEnjinia1701/altirig; DRAWING NO. ALR-DWG-115; REV P2; SHEET 1 of 1; SIZE ANSI B; SCALE 1:20; UNITS mm; PROJECTION; DRAWN Amish Chadha; Licensed CERN-OHL-S-2.0 · Design Molecule Lab · designmolecule.com; Generated from cad/src; do not edit by hand

WHERE IT GOES

This part in colour, its neighbours in grey

Scale 1:20; looking down (along -Z)

HOW TO MAKE IT AND HOW IT FITS
Cut a 790 dia disc from perforated sheet (22 mm square
holes on a 24.5 mm square pitch, 80 % open); file the rim smooth
Drill four 9 dia holes at 45, 135, 225 and 315 deg on a 764 circle
to match the tabs; fit them where the solid edge allows
Bolt to the tabs with M8 bolts, nuts and washers
The baffle comes out for the comparison runs without it
Check: 5 mm gap to the wall all round

Scale 1:20; looking at the front (along +Y)

Scale 1:20; looking at the right side (along -X)

AltiRig baffle plate

MATERIAL / NOTES
Perforated steel 2 thick, 80 % open

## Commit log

2026-10-03 AltiRig at TRL 3: constructable design (kit 1.7.0)
    Problem, concept and requirements; sizing calculations; CAD model, STEP and STL; general arrangement drawing; bill of materials; build plan with making sketches, joint close-ups and step pictures; design decisions register (design choices decided under Amish's 2026-10-03 pre-approval; requirement decisions open for Amish); TRL 2 and TRL 3 review; photoreal renders and storefront card. Private until Amish opens it.
    [altirig-assembly.step, altirig-assembly.stl, altirig-stand.step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]
2026-10-04 Carry Amish's round 2 requirement decisions into the design
    Amish approved all 47 recommendations on 2026-10-03 ("i approve all of the 47 recommendations provided by you. Execute them."). Each repo gains a decision record (DDR-003, or the next free number for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
    [bom.csv, results.csv]
2026-10-04 Carry Amish's round-2 and round-3 decisions into the design
    Amish approved all 46 round-2 recommendations ("i agree with all the 46 recommendations you provided. please proceed.") and all round-3 recommendations ("For round 3, I agree with all your proposed r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
    [altirig-assembly.step, altirig-stand.step, altirig-vessel.step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]

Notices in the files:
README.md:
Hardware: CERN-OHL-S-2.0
